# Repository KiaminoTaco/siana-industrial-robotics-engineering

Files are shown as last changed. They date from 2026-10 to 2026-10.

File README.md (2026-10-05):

# SIANA | Industrial Robotics Engineering

<p align="center">
  <strong>TGV Inspection Robot</strong><br>
  Mechanical Engineering · Electrical Engineering · Electronics · Embedded Robotics · Interface Engineering · System Integration
</p>

<p align="center">
  
  
  
</p>

<p align="center">
  <strong>Team Contact:</strong> <a href="mailto:a.elhaoudar@edu.umi.ac.ma">a.elhaoudar@edu.umi.ac.ma</a>
</p>

---

## Project Image

<p align="center">
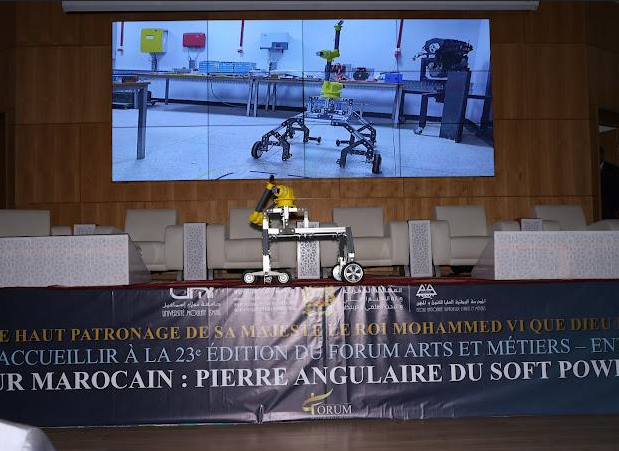
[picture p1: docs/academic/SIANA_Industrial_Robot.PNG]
SIANA Industrial Robot
  
</p>

<p align="center">
  <strong>SIANA Industrial Inspection Robot</strong><br>
  Main project platform and engineering integration target
</p>

---

# 01 | PROJECT OVERVIEW

The **TGV Inspection Robot** is an industrial robotic platform developed for automated visual inspection of high-speed train undercarriages at SIANA maintenance facilities.

Our project brings together multiple engineering disciplines, including mechanical design, electrical systems, embedded control, sensing, robotic manipulation, onboard computing, communication, operator interfaces, computer vision, and artificial intelligence.

Through this repository, we document our multidisciplinary engineering work and present the architecture, technologies, interfaces, documentation, and technical evidence associated with the project.

Our objective is to provide a clear technical view of the robot and to show how the different engineering disciplines interact to form one integrated industrial robotic system.

---

# 02 | ENGINEERING SCOPE

We approached the project as an integrated industrial robotic system rather than as a collection of independent subsystems.

```text
                    TGV INSPECTION ROBOT
                            |
        +-------------------+-------------------+
        |                   |                   |
        v                   v                   v
   MECHANICAL          ELECTRICAL          ELECTRONICS
        |                   |                   |
        +-------------------+-------------------+
                            |
                            v
                    EMBEDDED CONTROL
                            |
                            v
                   ONBOARD COMPUTING
                            |
             +--------------+--------------+
             |                             |
             v                             v
       ROBOT CONTROL                 AI / VISION
             |                             |
             +--------------+--------------+
                            |
                            v
                  OPERATOR INTERFACE
                            |
                            v
                  INSPECTION WORKFLOW
```

### Main Engineering Domains

| Domain | Main Content |
|---|---|
| Mechanical | Chassis, wheels, robotic arm, fairing, CAD, drawings |
| Electrical | Power architecture, wiring, protection, actuators |
| Electronics | Controllers, sensors, communication interfaces |
| Embedded | Robot control, telemetry, low-level interfaces |
| Interface | Operator control, visualization, sensor feedback |
| Software | Robot-side and station-side software |
| AI | Detection, inference, and model-training workflow |
| Maintenance | Preventive maintenance and service procedures |
| Integration | Mechanical, electrical, electronic, and software interfaces |

---

# 03 | SYSTEM ARCHITECTURE

Our project is organized around a combination of physical hardware, embedded systems, onboard computing, software, communication, and operator interfaces.

The software platform described in our project is divided into two principal environments.

## Robot-Side System

The robot-side software supports functions such as:

- Autonomous navigation
- Camera operation
- Lighting control
- Onboard AI inference
- Wireless communication
- Battery and system-health monitoring
- Operator commands
- Synchronization of inspection data

## Station-Side Platform

The control station provides functions related to:

- Robot management
- Inspection-session management
- Telemetry visualization
- Video processing and storage
- AI model management
- Defect records
- Inspection reports
- Authentication and access control
- Notifications and alerts
- Audit logging

## Communication Layer

Our project documentation identifies communication technologies including:

```text
MQTT
 |
 +---- Command messaging
 +---- Robot telemetry

WebRTC
 |
 +---- Low-latency video streaming

Object Storage
 |
 +---- Inspection video
 +---- High-resolution images
```

The software context includes technologies such as:

- Python
- FastAPI
- PostgreSQL
- Redis
- MinIO
- MQTT
- WebRTC
- Docker

---

# 04 | MECHANICAL ENGINEERING

Our mechanical work focuses on the physical structure and integration of the inspection robot.

## Mechanical Architecture

The documented robot includes:

- Aluminium-profile chassis
- Driven wheels
- Caster wheels
- Removable protective fairing
- Robotic arm
- Camera support
- Mechanical mounting interfaces
- Maintenance-accessible components

## Mechanical Engineering Activities

Our mechanical documentation is organized around:

```text
mechanical/
|
+-- cad/
|   +-- assemblies/
|   +-- chassis/
|   +-- arm/
|   +-- wheel-system/
|
+-- drawings/
|   +-- definition/
|   +-- assembly/
|   +-- manufacturing/
|
+-- schematics/
|
+-- maintenance/
|
+-- README.md
```

### Mechanical Evidence

Depending on publication and ownership constraints, the mechanical section can contain:

- CAD assemblies
- Part models
- Definition drawings
- Assembly drawings
- STL files
- Mechanical research
- Maintenance documentation

These materials help us document the design choices, interfaces, physical architecture, and integration of the robot.

---

# 05 | ELECTRICAL ENGINEERING

Our electrical engineering work documents how energy, actuators, sensors, controllers, and protection systems are interconnected.

## Main Topics

Our electrical documentation covers areas such as:

- Battery architecture
- Power distribution
- DC/DC conversion
- Motor supply
- Controller supply
- Sensor supply
- Wiring
- Electrical protection
- Emergency-stop architecture
- Actuator interfaces
- Communication wiring

## Electrical Structure

```text
electrical/
|
+-- schematics/
|   +-- power/
|   +-- controllers/
|   +-- sensors/
|   +-- actuators/
|   +-- communication/
|   +-- emergency-stop/
|
+-- wiring/
|
+-- protection/
|
+-- variants/
|
+-- bom/
|
+-- README.md
```

### Configuration Control

Our project material may contain different electrical configurations or design variants.

We keep these variants identifiable rather than silently merging them into a single configuration.

When the available project evidence does not establish a final validated configuration, we preserve the different documented variants and identify them accordingly.

---

# 06 | ELECTRONICS & EMBEDDED ROBOTICS

Our robot combines sensors, controllers, embedded systems, and onboard computing.

The project material identifies technologies including:

```text
Sensors
   |
   v
Microcontrollers
   |
   +---- ESP32
   +---- Arduino Mega
   |
   v
Onboard Computing
   |
   +---- Jetson Nano
   +---- Raspberry Pi 5
   |
   v
Robot Functions
   |
   +---- Control
   +---- Telemetry
   +---- Communication
   +---- Vision / AI
```

Our electronics documentation is organized around:

```text
electronics/
|
+-- architecture/
+-- wiring/
+-- controllers/
+-- sensors/
+-- communication/
+-- component-docs/
+-- README.md
```

The embedded section distinguishes between:

- Verified project source code
- Project architecture
- Representative code
- Reconstructed examples
- Integration work

This distinction helps us maintain a clear boundary between the complete team project and individual examples or supporting material.

---

# 07 | ROBOT CONTROL INTERFACE

We developed and documented an interface layer for robot control and monitoring.

```text
interface/
|
+-- code/
|   +-- RobotArmInterface.pde
|   +-- RobotControlerInterface.pde
|
+-- presentation/
|
+-- protocol/
|
+-- diagrams/
|
+-- README.md
```

## Interface Functions

The supplied Processing interface includes functionality related to:

- Five-joint robot control
- Target-angle commands
- Current-angle feedback
- HOME positioning
- Robotic-arm visualization
- Temperature monitoring
- Humidity monitoring
- Distance measurements
- Sensor-history graphs
- Serial communication
- Connection-status monitoring

### Joint Model

| Joint | Documented Range |
|---|---:|
| Base | -180° to +180° |
| Shoulder | 0° to 180° |
| Elbow | 0° to 180° |
| Pan | 0° to 180° |
| Tilt | 0° to 180° |

The interface protocol uses serial communication at **115200 baud**.

`RobotArmInterface.pde` is based on the supplied Processing interface source.

`RobotControlerInterface.pde` is included as a companion interface/integration component and should be interpreted according to the available project attribution evidence.

---

# 08 | SOFTWARE & AI CONTEXT

Our software platform supports the inspection workflow from robot operation to data management and analysis.

## Robot-Side Software

```text
Navigation
   |
Camera / Lighting
   |
AI Inference
   |
Telemetry
   |
Communication
   |
Inspection Data
```

## Station-Side Software

```text
Robot Management
       |
Inspection Sessions
       |
Video / Image Management
       |
Defect Records
       |
AI Training
       |
Reports / Analytics
```

### Technologies Documented in the Project

| Category | Technologies |
|---|---|
| Backend | Python, FastAPI |
| Database | PostgreSQL |
| Cache | Redis |
| Object Storage | MinIO |
| Messaging | MQTT |
| Video | WebRTC |
| Deployment | Docker |
| AI | Machine-learning / YOLO-based workflow |

This software context shows how our digital systems support the physical robot and the overall inspection workflow.

---

# 09 | MAINTENANCE ENGINEERING

We treat maintenance as an important part of the robot engineering lifecycle.

Our maintenance documentation can be organized as:

```text
maintenance/
|
+-- manuals/
+-- preventive/
+-- inspection-checklists/
+-- maintenance-history/
+-- component-service/
+-- README.md
```

Typical documented maintenance subjects include:

- Chassis and fairing inspection
- Wheel-support inspection
- Wheel-play inspection
- Caster inspection
- Cleaning and corrosion checks
- Emergency-stop checks
- Movement-warning checks
- Robotic-arm fastening
- Sealing inspection
- Periodic general inspection

The maintenance section connects our physical design with long-term industrial operation, serviceability, and preventive maintenance.

---

# 10 | ENGINEERING DOCUMENTATION

Our documentation layer explains the engineering work without unnecessarily duplicating every source file.

## Academic Project Image

The main project image used in this README is stored at:

```text
docs/academic/SIANA_Industrial_Robot.PNG
```

The image is referenced using a repository-relative path so that GitHub can render it directly from the repository.

## Documentation Structure

```text
documentation/
|
+-- system-architecture.md
+-- mechanical-engineering.md
+-- electrical-engineering.md
+-- electronics-engineering.md
+-- embedded-systems.md
+-- interface-engineering.md
+-- system-integration.md
+-- testing-and-validation.md
+-- maintenance-engineering.md
+-- contribution.md
```

Our documentation follows the principle:

```text
DOCUMENTATION
     |
     +---- explains the engineering
     |
     v
ENGINEERING FILES
     |
     +---- support the engineering
```

---

# 11 | ENGINEERING EVIDENCE & ATTRIBUTION

Because this is a multidisciplinary team project, we distinguish between different levels of attribution.

| Status | Meaning |
|---|---|
| Explicitly documented | The project material directly identifies the contribution |
| Project-supported | The contribution is strongly supported by technical evidence |
| Team-level | The work belongs to the project team |
| Inferred | The interpretation is derived from available evidence |
| Other contributor | The source identifies another contributor |
| Uncertain | The available material is insufficient to verify ownership |

## Source Priority

When documenting our project, we follow this priority:

```text
1. Direct project files
2. Technical report
3. Project documentation
4. Team GitHub repository
5. Project images / videos
6. CV for professional context
7. Team explanations and clarifications
8. General engineering knowledge
```

This hierarchy helps us avoid presenting assumptions as confirmed project facts.

---

# 12 | PROJECT VARIANTS

Our project material may contain different technical variants created during the development process.

Examples can include:

- Alternative controller architectures
- Alternative battery configurations
- Alternative motor selections
- Alternative sensor arrangements
- Different software architecture stages

We keep these variants identifiable as documented development states until the available project evidence establishes the final validated configuration.

This allows us to preserve the development history and better understand how the engineering architecture evolved.

---

# 13 | REPOSITORY STRUCTURE

```text
SIANA-Industrial-Robotics-Engineering/
|
+-- mechanical/
|   +-- cad/
|   +-- drawings/
|   +-- schematics/
|   +-- maintenance/
|
+-- electrical/
|   +-- schematics/
|   +-- wiring/
|   +-- protection/
|   +-- variants/
|   +-- bom/
|
+-- electronics/
|   +-- architecture/
|   +-- wiring/
|   +-- controllers/
|   +-- sensors/
|
+-- embedded/
|
+-- interface/
|   +-- code/
|   +-- presentation/
|   +-- protocol/
|   +-- diagrams/
|
+-- electromechanical-integration/
|
+-- integration/
|
+-- maintenance/
|
+-- documentation/
|
+-- software-context/
|
+-- media/
|
+-- contribution/
|
+-- tests/
|
+-- bom/
|
+-- README.md
```

There is intentionally **no separate `calculations/` section** in this repository structure.

---

# 14 | HOW TO REVIEW THIS PROJECT

A technical reviewer can follow the project through the following path:

```text
                    README
                      |
          +-----------+-----------+
          |           |           |
          v           v           v
      MECHANICAL   ELECTRICAL  ELECTRONICS
          |           |           |
          +-----------+-----------+
                      |
                      v
                EMBEDDED SYSTEMS
                      |
                      v
                INTERFACE LAYER
                      |
                      v
              SYSTEM INTEGRATION
                      |
                      v
                MAINTENANCE
```

For detailed verification, each engineering explanation should lead to the corresponding project evidence, such as:

- CAD file
- Technical drawing
- Electrical schematic
- Wiring documentation
- Source code
- Test result
- Maintenance document
- Photograph or video

---

# 15 | ENGINEERING APPROACH

We follow a multidisciplinary engineering workflow:

```text
Requirements
     |
     v
System Architecture
     |
     v
Mechanical / Electrical Design
     |
     v
Electronics & Embedded Control
     |
     v
Software / Interface
     |
     v
System Integration
     |
     v
Testing & Validation
     |
     v
Maintenance
```

Our objective is to demonstrate how the different engineering disciplines interact to create a functional industrial robotic inspection system.

We consider the robot as one complete engineering system in which mechanical, electrical, electronic, embedded, software, interface, and maintenance aspects must work together.

---

# 16 | TEAM PROJECT POSITIONING

This repository represents our multidisciplinary work on an industrial robotics project.

Our work covers and connects:

- Mechanical design
- CAD and technical drawings
- Electrical architecture
- Electronics
- Embedded systems
- Robotic-arm integration
- Sensor integration
- Operator interfaces
- System integration
- Maintenance engineering
- Technical documentation
- Software and AI context

The emphasis of this repository is on the **complete engineering system** and on how the physical, electrical, and digital components of the robot operate together.

## Contact

For project-related information:

**Email:** [a.elhaoudar@edu.umi.ac.ma](mailto:a.elhaoudar@edu.umi.ac.ma)

---

# 17 | COPYRIGHT, OWNERSHIP & PUBLICATION

This repository documents a **team engineering project**.

It should not imply individual ownership of every project artifact.

Before public publication, we should verify:

- Whether project documents may be redistributed
- Teammate-owned source code
- Institutional documentation
- CAD and manufacturer documents
- Confidential information
- Required original attribution

Where authorship is uncertain, we preserve that uncertainty rather than assigning unsupported ownership.

The purpose of this repository is to provide an organized technical representation of our engineering project while respecting the ownership and attribution of the different contributors and project sources.

---

<p align="center">
  <strong>SIANA — Industrial Robotics Engineering</strong><br>
  TGV Inspection Robot
</p>

<p align="center">
  Mechanical · Electrical · Electronics · Embedded · Interface · Integration · Maintenance
</p>

<p align="center">
  <strong>Team Contact:</strong> <a href="mailto:a.elhaoudar@edu.umi.ac.ma">a.elhaoudar@edu.umi.ac.ma</a>
</p>

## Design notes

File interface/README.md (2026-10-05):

# Robot Interface

Operator-facing interface for the SIANA robotic arm and sensor system.

Includes:
- five-joint control
- serial communication
- target/current joint angles
- sensor monitoring
- arm visualization
- connection/status handling

See `presentation/` for the interface explanation and architecture.
See `code/` for the Processing implementation and controller abstraction.
See `protocol/` for the serial communication format.

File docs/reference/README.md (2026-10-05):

# Reference Material

The repository contains the project software package and selected supplied reference assets.

The following categories were considered during consolidation:

- global technical report;
- electrical engineering report;
- mechanical engineering package;
- maintenance material;
- Robot Control Interface material;
- SIANA APP software package;
- project specification/cahier des charges;
- system architecture material.

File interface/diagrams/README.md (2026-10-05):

# Interface Diagrams

Reserved for interface architecture, operator workflow, serial-flow diagrams and screenshots.

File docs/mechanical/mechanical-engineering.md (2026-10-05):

# Mechanical Engineering

The supplied mechanical project material covers the robot chassis and robotic-arm structure, including CAD assemblies, STEP/STL models, technical drawings, arm joints, supports, couplings, sheet-metal components and maintenance documentation.

Mechanical design is represented as a team-level contribution. The electrical contributor also provided supporting integration/research input, but the repository does not attribute the complete mechanical design to one person.

Authoritative design files are intentionally reserved for manual insertion:

```text
hardware/mechanical/cad/
hardware/mechanical/drawings/ 
```

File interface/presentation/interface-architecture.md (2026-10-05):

# Interface Architecture

```text
Operator
   |
   v
RobotArmInterface (Processing)
   |
   v
RobotControlerInterface
   |
   | Serial / USB
   v
Embedded Robot Controller
   |
   +--> Robotic arm
   +--> Sensors
   +--> Status / safety
```

The graphical interface is an operator layer; safety-critical functions should remain independently enforced by the embedded controller and hardware.

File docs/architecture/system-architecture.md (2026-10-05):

# System Architecture

The SIANA project uses a distributed architecture in which physical actuation, embedded control, high-level computation, AI/perception and operator/station software are separated into cooperating layers.

## Main layers

1. **Physical layer** — chassis, motors, arm actuators and sensors.
2. **Embedded layer** — real-time motor/servo and sensor interfacing.
3. **High-level computation** — Raspberry Pi / Jetson-oriented computation and coordination.
4. **AI/perception** — image processing and defect-detection workflows.
5. **Station layer** — web interface, services, databases, communication and reporting.
6. **Dedicated Robot Control Interface** — arm movement and associated sensor interaction.

The supplied SIANA APP adds a station-side software implementation with a React/TypeScript frontend and FastAPI-oriented backend services, PostgreSQL initialization and Nginx/Docker infrastructure.

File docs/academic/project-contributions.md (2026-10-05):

# Project Contributions and Scope of Responsibility

## 1. Team project

SIANA is a multidisciplinary engineering project. Mechanical design, electrical engineering, embedded control, software, AI, inspection and system integration are interconnected team activities.

## 2. Primary individual responsibility

The principal individual responsibility represented in this repository is the **electrical part**.

This includes the integration of motors and sensors and their connection to the software control layer.

## 3. Software integration

The electrical/control contribution extends into the Python/Arduino software because the physical devices cannot be considered independently from their control interfaces. The relevant work therefore includes mapping application commands to actuator behavior and bringing sensor data into the software layer.

## 4. Robot Control Interface

The dedicated Robot Control Interface was developed collaboratively with the teammate responsible for the AI component.

The contribution represented here is the hardware-oriented side of that collaboration: integration of motors, sensors and embedded control with the interface software.

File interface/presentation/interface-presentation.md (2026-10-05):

# Robot Control & Visualization Interface

I use this interface as the operator-facing layer for controlling and monitoring the robotic arm.

## Controlled joints

| Index | Joint | Range |
|---:|---|---|
| 0 | Base | -180° to +180° |
| 1 | Shoulder | 0° to 180° |
| 2 | Elbow | 0° to 180° |
| 3 | Pan | 0° to 180° |
| 4 | Tilt | 0° to 180° |

## Functions

- five joint controls
- HOME position
- arm visualization
- joint-angle display
- temperature/humidity monitoring
- two distance channels
- sensor history graphs
- serial communication
- connection status

The supplied implementation uses Processing serial communication at 115200 baud.

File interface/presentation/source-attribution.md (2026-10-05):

# Interface Source Attribution

`RobotArmInterface.pde` is based directly on the Processing source supplied with this portfolio update.

It contains serial communication, five joint controls, target-angle transmission, feedback parsing, sensor parsing, arm visualization, graphs and status handling.

`RobotControlerInterface.pde` is a companion portfolio integration layer organizing the communication/control boundary. It is not automatically claimed as original team source code.

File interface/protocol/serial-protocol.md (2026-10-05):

# Serial Communication Protocol

Default transport:

```text
115200 baud
newline-terminated messages
```

Command:

```text
BASE,SHOULDER,ELBOW,PAN,TILT
```

Sensor packet:

```text
S,TEMPERATURE,HUMIDITY,DISTANCE1,DISTANCE2
```

Joint feedback:

```text
BASE,SHOULDER,ELBOW,PAN,TILT
```

These formats are derived from the supplied Processing interface.

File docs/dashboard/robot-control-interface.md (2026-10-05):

# Robot Control Interface

## Scope

This interface is a dedicated operator interface for the **robotic arm and its associated sensors**.

It is not the full technical dashboard of the entire inspection robot.

## Control chain

```text
UI / operator command
        |
        v
Python/application layer
        |
        v
Serial / Arduino control
        |
        +------> Arm actuators
        |
        +------> Sensor acquisition
```

## Supplied implementation characteristics

The supplied interface material documents serial communication with the embedded controller at **115200 baud** and integration of robotic-arm motion with sensor visualization.

The broader SIANA APP supplied with the project is maintained separately under `software/siana-app/`. Its control panel includes emergency-stop state, manual override, speed control and movement-direction controls. That station UI represents a broader software platform and must not be conflated with the dedicated arm-and-sensor interface.

## Source location

```text
src/robot_control_interface/
```

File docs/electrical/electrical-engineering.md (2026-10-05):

# Electrical Engineering

## System role

The electrical subsystem links the power architecture, embedded controllers, sensors and actuators.

## Documented controllers

The project material discusses ESP32, Arduino Mega 2560, Raspberry Pi and NVIDIA Jetson platforms in a distributed architecture.

## Robotic arm

The robotic arm is described as a 6-DOF subsystem. The electrical documentation identifies an Arduino Mega 2560 as its dedicated controller and PWM-driven digital servomotors as its actuators.

A dedicated arm power path is used to limit voltage disturbance caused by servo current demand.

## Sensors

The supplied technical material covers:

- LiDAR for navigation and mapping;
- SRF10 ultrasonic sensors for obstacle detection around the arm;
- LM35 temperature sensing associated with motors;
- Sharp GP2Y0A02YK0F infrared distance sensing;
- camera/CSI imaging;
- IMU sensing;
- LoRa communications;
- CAN communications.

## Power and protection

The project studies battery supply, voltage conversion, distribution, motor/ESC power and protection measures including fusing and relay-based safety isolation.

## Individual contribution

The electrical contribution includes the integration of motors and sensors into the Python/Arduino control software and the associated hardware/software interface work.

## Design files

Authoritative electrical design files are intentionally left for manual addition:

```text
hardware/electrical/schematics/
hardware/electrical/pcb/
hardware/electrical/bom/
```

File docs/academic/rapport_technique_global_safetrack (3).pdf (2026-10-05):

École Nationale Supérieure d’Arts et Métiers

Meknès — Maroc

Prix InnovAM’26

# Dossier Technique Global

### Équipe SAFE TRACK

## Robot d’Inspection Intelligente Sous Caisse TGV

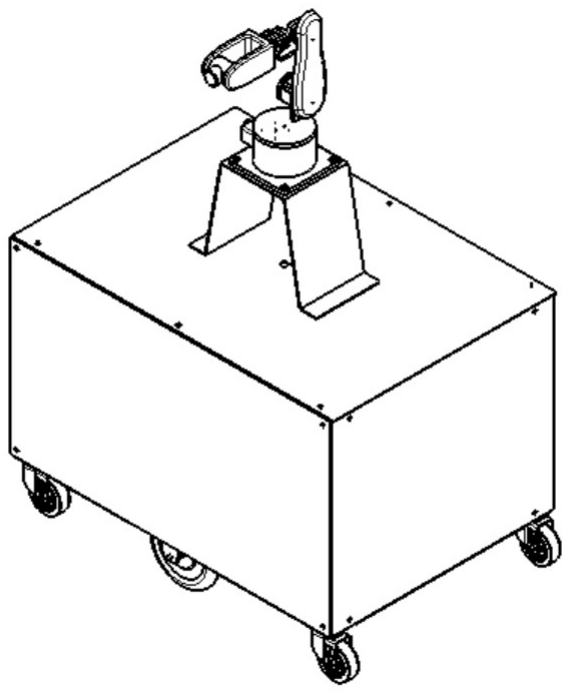
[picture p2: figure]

ELKHALFI ANOUAR Mécanique
BOUDRIKA Ilyass Logiciel/IA

HOUMMADI TAHA Logiciel/IA
ELHAOUDER AYMANE. Electro-mécanique

Février 2026

Partenaire industriel : SIANA | Compétition : InnovAM’26

# Remerciements

L’équipe Safe track tient à exprimer sa profonde gratitude envers toutes les personnes qui ont contribué à la réalisation de ce projet ambitieux.

Nous remercions chaleureusement la direction et le corps professoral de l’ENSAM Meknès pour leur accompagnement pédagogique et leur soutien logistique tout au long de cette compétition.
Nos remerciements vont également aux ingénieurs et techniciens de la SIANA pour les informations précieuses sur l’environnement réel d’exploitation des TGV AL BORAQ. Un remerciement particulier au comité organisateur d’InnovAM’26 pour l’organisation de cette compétition qui stimule l’innovation dans le domaine du génie industriel, et aux équipes des éditions précédentes pour leurs rapports qui nous ont servi d’inspiration. Enfin, nous remercions nos familles et nos proches pour leur soutien indéfectible durant cette période de travail intense.

L’équipe Safe track
Février 2026

ii / 37

# Table des Matières

Remerciements | ii
Liste des Acronymes | vii
Résumé Exécutif | 1
1 Introduction et Contexte | 3
2 Partie Mécanique | 6

iii / 37

iv / 37 | SIANA — InnovAM’26
3 Partie Électronique | 14
4 Partie Logiciel et Intelligence Artificielle | 17
5 Plan de Maintenance Préventive | 27
6 Impact et Bénéfices | 29
7 Perspectives et Évolutions | 31
Conclusion | 32
Appendices | 33
A Plans Techniques CATIA | 34
B Budget des Composants | 36

Robot d’Inspection Intelligente sous Caisse TGV

# Liste des Figures

1.1 Progression du projet InnovAM sur trois éditions | | 3
1.2 Contexte d’utilisation : rame TGV AL BORAQ en position d’inspection. . . | 4
1.3 Architecture globale du système robot SIANA | | 5
2.1 Vues CATIA du robot SIANA | | 7
2.2 Mesure CATIA : masse et centre de gravité | | 8
2.3 Profilé aluminium 8 — 40×40 | | 8
2.4 Roue motrice 8.5” (350W, 36V) | | 8
2.5 Score pondéré : châssis soudé vs profilé boulonné | | 9
2.6 Bras robotique 5 axes — conception CATIA | | 12
3.1 Architecture électronique distribuée multi-calculateurs | | 14
4.1 Architecture globale : Robot autonome + Plateforme Microservices | | 17
4.2 Boucle d’amélioration continue automatique du modèle IA | | 18
4.3 Pipeline de détection YOLOv11 — de l’image brute aux fissures détectées. . | 19
4.4 Courbes d’entraînement YOLOv11s — pertes (box, classification, DFL), mAP
et précision/rappel sur 30 époques | 21
4.5 Prédictions YOLOv11s sur le jeu de test — boîtes bleues = fissures détectées
avec score de confiance (≥ 0,25) | | 22
4.6 Dashboard — Vue d’ensemble flotte et statistiques temps réel | | 25
4.7 Page inspection — Streaming WebRTC + panneau de contrôle intuitif. . . . | 25
4.8 Vue flotte — Statuts robots | | 26
4.9 Gestion anomalies — Filtres avancés | | 26
6.1 Indicateurs d’impact clés | | 29
7.1 Roadmap d’évolution du système SIANA | | 31
A.1 Dessin d’ensemble coté | | 34
A.2 Plans cotés : châssis et support roue motrice | | 35
A.3 Plans cotés : platine roue folle et tôles de carénage | | 35

v / 37

# Liste des Tableaux

2.1 Comparaison multicritère : châssis soudé vs profilé boulonné | | 9
2.2 Comparaison multicritère : choix de la locomotion | | 10
2.3 Spécifications du bras robotique 5 axes | | 12
2.4 Comparaison dimensionnelle robot vs contraintes CDC | | 13
3.1 Distribution des rôles des calculateurs embarqués | | 15
3.2 Spécifications des capteurs embarqués | | 15
4.1 Caractéristiques du jeu de données de détection de fissures | | 20
4.2 Hyperparamètres d’entraînement du modèle YOLOv11s | | 20
4.3 Performances du modèle YOLOv11s pour la détection de fissures | | 23
4.4 Stack technologique complet de la plateforme | | 24
5.1 Programme de maintenance préventive robot SIANA | | 27
6.1 Indicateurs de performance clés et méthodes de mesure | | 30

vi / 37

# Liste des Acronymes

RGVM | Rame à Grande Vitesse Marocaine
ES | Examen en Service
IA | Intelligence Artificielle
TGV | Train à Grande Vitesse
RDM | Résistance des Matériaux
CG | Centre de Gravité
IP | Indice de Protection
BMS | Battery Management System
IMU | Inertial Measurement Unit
LiDAR | Light Detection and Ranging
MQTT | Message Queuing Telemetry Transport
WebRTC | Web Real-Time Communication
JWT | JSON Web Token
RBAC | Role-Based Access Control
KPI | Key Performance Indicator
GMAO | Gestion de Maintenance Assistée par Ordinateur
CDC | Cahier des Charges

vii / 37

# Résumé Exécutif

Innovation Centrale
Système robotique complet intégrant mécanique avancée, électronique distribuée et intelligence artificielle embarquée pour automatiser l’inspection sous caisse des rames TGV AL BORAQ.

## Le Problème

L’inspection manuelle ES (Examen en Service) sous caisse des rames RGVM nécessite
actuellement | 3–4 heures | par opérateur dans un environnement contraint. Cette approche
présente des risques majeurs :
- Conditions dangereuses pour les opérateurs (espace confiné, projections)
- Fatigue visuelle entraînant des erreurs humaines
- Temps d’inspection impactant la disponibilité des rames
- Traçabilité incomplète des contrôles effectués

## Notre Solution

Un robot d’inspection autonome à architecture modulaire :

1 / 37

2 / 37 | SIANA — InnovAM’26
Partie | Description | Innovation
Mécanique | Châssis soudé alu 40×40, 2 roues motrices, bras 5 axes, carénage IP66 | Conception CATIA, RDM complet
Électronique | Jetson Nano + RPi5 + ESP32,
| LiDAR, caméra IMX708,
| batterie 48V

Architecture distribuée

Logiciel /
IA

9 microservices, IA embarquée, WebRTC, interface React

Amélioration continue auto

1

# Introduction et Contexte

## 1.1 Contexte du Projet InnovAM’26

La compétition InnovAM’26 s’inscrit dans un cycle pluriannuel de conception progressive d’un robot d’inspection sous caisse TGV, organisée par l’ENSAM Meknès en partenariat
avec la SIANA. L’édition 2026 constitue l’étape de | déploiement industriel | avec un robot
aux dimensions réelles.

2024
Plans & Idées

2025
Prototype Réduit

2026
Robot Réel

Édition actuelle

Figure 1.1 – Progression du projet InnovAM sur trois éditions.

## 1.2 La Rame TGV AL BORAQ — Contexte d’Inspec-

## tion

Les rames RGVM (Rame à Grande Vitesse Marocaine) AL BORAQ circulent sur la ligne à grande vitesse Kénitra–Tanger. Leur maintenance exige une inspection régulière des bogies, essieux, freins, suspensions et transmissions dans des fosses d’inspection d’une longueur pouvant atteindre environ 200 m.

3 / 37

4 / 37 | SIANA — InnovAM’26

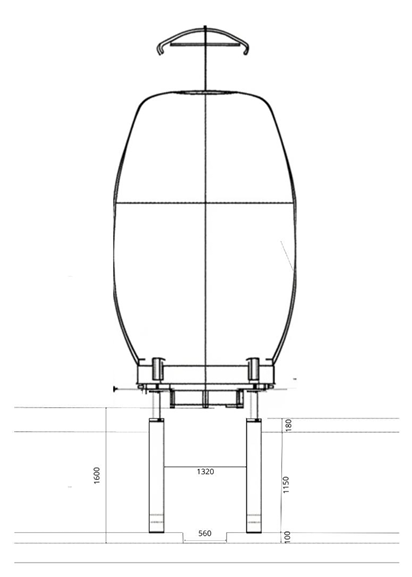
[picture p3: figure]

Figure 1.2 – Contexte d’utilisation : rame TGV AL BORAQ en position d’inspection.

## 1.3 Cahier des Charges — Exigences Fondamentales

Chapitre 1. Introduction et Contexte | 5 / 37

Exigences Clés — Cahier des Charges InnovAM’26

Performances

- Vitesse : 3–5 km/h (bonus +20%)
- Autonomie : ≥ 4 heures
- Portée pilotage : ≥ 50 m

Vision & Communication

- Full HD 1920×1080, 30 fps
- Latence streaming < 500 ms
- Transportable (2 personnes max)

Bonus (Points supplémentaires)

- Étanchéité IP6X + IPX6
- Détection automatique d’anomalies par IA

## 1.4 Architecture Globale du Système SIANA

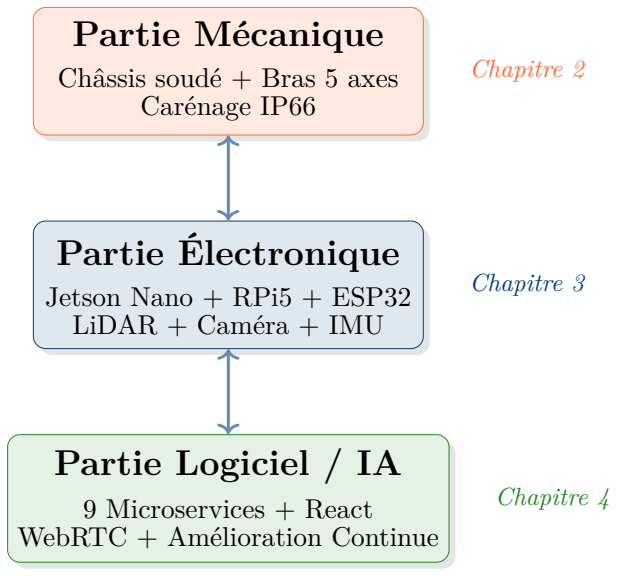
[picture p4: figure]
Partie Mécanique; Châssis soudé + Bras 5 axes Carénage IP66; Partie Électronique; Jetson Nano + RPi5 + ESP32 LiDAR + Caméra + IMU; Partie Logiciel / IA; 9 Microservices + React WebRTC + Amélioration Continue; Chapitre 2; Chapitre 3; Chapitre 4

Figure 1.3 – Architecture globale du système robot SIANA.

2

# Partie Mécanique

Dossier Détaillé
Ce chapitre présente une synthèse de la conception mécanique. Pour plus de détails, veuillez consulter le rapport détaillé de la partie mécanique ainsi que les plans techniques CATIA joints en annexe (Annexe A).

## 2.1 Architecture Mécanique Retenue

Configuration finale :

- Locomotion : 2 roues motrices centrales (type trottinette) + 4 roues folles (coins)
- Châssis : Profilés aluminium rainure 8 (40×40 mm), assemblage soudé
- Carénage : Tôles aluminium démontables (vis à tête fraisée)
- Bras : 5 axes, masse totale ≈ 5 kg, portée 1600 mm

6 / 37

Chapitre 2. Partie Mécanique | 7 / 37

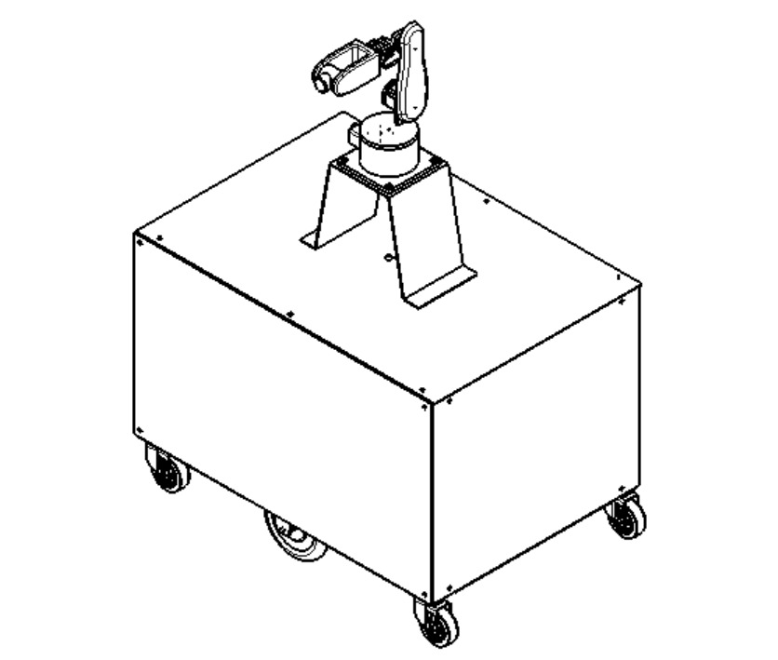
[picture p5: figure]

(a) Vue isométrique — Conception CATIA V5.

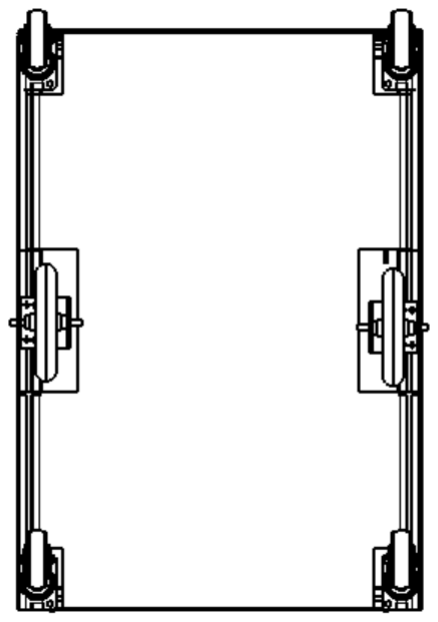
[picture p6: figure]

(b) Vue dessous : implantation des roues.

Figure 2.1 – Vues CATIA du robot SIANA.

## 2.2 Données de Conception

### 2.2.1 Dimensions Finales

Longueur

## L = 1000 mm

Largeur

## W = 700 mm

Hauteur

## H = 656 mm

Vitesse nominale : v = 3,6 km/h = 1,0 m/s

### 2.2.2 Masse et Centre de Gravité (CATIA)

Données Inertielles

m = 66,556 kg | Gx = −154,0 mm | Gy = 4,8 mm | Gz = 196,9 mm

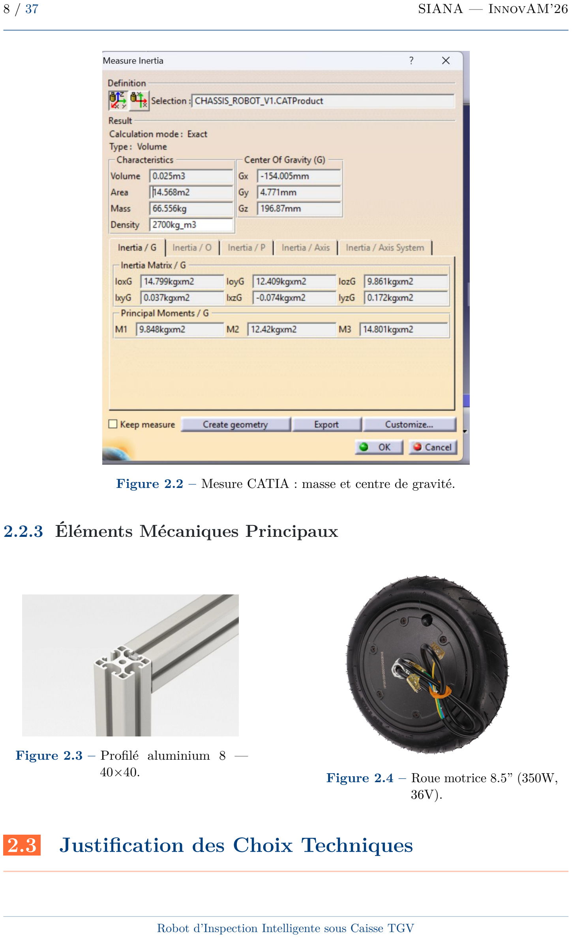
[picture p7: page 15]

8 / 37 | SIANA — InnovAM’26

Figure 2.2 – Mesure CATIA : masse et centre de gravité.

### 2.2.3 Éléments Mécaniques Principaux

Figure 2.3 – Profilé aluminium 8 —
40×40. | Figure 2.4 – Roue motrice 8.5” (350W,
| 36V).

## 2.3 Justification des Choix Techniques

Chapitre 2. Partie Mécanique | 9 / 37

### 2.3.1 Châssis : Soudé vs Profilé Boulonné

Table 2.1 – Comparaison multicritère : châssis soudé vs profilé boulonné.

Critère | Poids | Soudé | Boulonné
Rigidité | 5 | 5 | 3
Coût | 4 | 4 | 3
Maintenance | 3 | 2 | 5
Résistance vibration | 5 | 5 | 3
Fabrication | 3 | 4 | 4
Poids | 2 | 4 | 4
Total pondéré | | 89 | 80
Châssis soudé | Profilé boulonné

0

20

40

60

80

100 | 89
80
Score pondéré

Figure 2.5 – Score pondéré : châssis soudé vs profilé boulonné.

10 / 37 | SIANA — InnovAM’26

### 2.3.2 Locomotion : 2FWD vs 4WD vs Chenilles

Table 2.2 – Comparaison multicritère : choix de la locomotion.

Critère | Poids | 2FWD | 4WD | Chenilles
Coût global | 5 | 5 | 2 | 2
Complexité mécanique | 4 | 4 | 2 | 2
Maintenance | 4 | 4 | 2 | 2
Adhérence sol glissant | 5 | 3 | 4 | 5
Stabilité | 3 | 4 | 4 | 3
Efficacité énergétique | 3 | 4 | 3 | 2
Score pondéré | | 96 | 67 | 66

## 2.4 Dimensionnement de la Traction

### 2.4.1 Hypothèses de Calcul

- Masse totale : m = 66,556 kg
- Diamètre roue : D = 216 mm
- Rayon : r = 0,108 m
- Vitesse nominale : v = 1,0 m/s
- Accélération : a = 0,5 m/s

2

- Coef. roulement : Crr = 0.03

### 2.4.2 Résultats du Calcul

ωroue =

v
r
= 9,26 rad/s | ⇒ | nroue ≈ 88 rpm | (2.1)
Freq = Crr · m · g + m · a = 19.59 + 33.28 = 52,87 N | (2.2)
Ttot = Freq × r = 5,71 N · m | ⇒ | Troue = 2,86 N · m | (2.3)
Preq = Freq × v = 52,87W | (2.4)

Chapitre 2. Partie Mécanique | 11 / 37

Moteur Sélectionné
Hub motor Transtecno 350 W, 36 V intégré dans la roue 8.5” :
- Puissance nominale : 350 W (marge de 6,6×)
- Couple nominal : ≫ 5.7 N·m requis

## 2.5 Dimensionnement Structurel (RDM)

### 2.5.1 Contrainte de Flexion — Longerons

w =

0.5 × P
L
= 326,5 N/m | (2.5)

Mmax =

wL²
8
= 40,81 N · m | ⇒ | σmax = 9,07 MPa | (2.6)

Avec coefficient majorant k = 2.5 :

σmax,maj = 22,7 MPa | ⇒ | F Sσ =

140
22.7

≈ 6.2

### 2.5.2 Flèche Maximale

δmax =

5wL⁴
384EI
= 0,684 mm | ⇒ | δmax,maj = 1,71 mm

Conformité Flèche
Critère : δ ≤ L/300 = 3,33 mm ✓ Conforme

### 2.5.3 Stabilité Anti-Basculement

ay,tip = g ·

W/2

hCG

= 17,44 m/s

2 ≈ 1.78 g

✓ Conforme — Le robot résiste à l’inclinaison dans les conditions opérationnelles.

## 2.6 Bras Robotique — Architecture 5 Axes

12 / 37 | SIANA — InnovAM’26

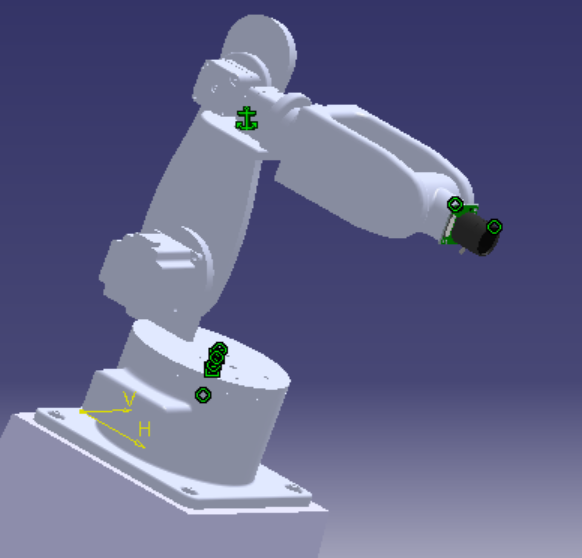
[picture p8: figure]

Figure 2.6 – Bras robotique 5 axes — conception CATIA.

Table 2.3 – Spécifications du bras robotique 5 axes.

Axe | Fonction | Course | Couple
A1 | Rotation base (yaw) | 360◦ | – (inertie)
A2 | Épaule basse (pitch) | 180◦ | 7–10 N·m
A3 | Épaule haute (pitch) | 180◦ | 2.3–3.1 N·m
A4 | Coude (pitch) | 360◦ | 1.1–1.5 N·m
A5 | Poignet/caméra | libre | 0.18–0.24 N·m

## 2.7 Conformité Dimensionnelle et Protection

Chapitre 2. Partie Mécanique | 13 / 37

### 2.7.1 Conformité avec Cahier des Charges

Table 2.4 – Comparaison dimensionnelle robot vs contraintes CDC.

Critère | Référence | Robot | Statut
Largeur disponible fosse | 1320 mm | 700 mm | ✓
Longueur robot | Volumes dispo | 1000 mm | ✓
Portée inspection | ≥1500 mm | 1600 mm | ✓

### 2.7.2 Protection IP6X / IPX6

Étanchéité Industrielle

L’étanchéité est assurée par un carénage complet en tôles aluminium avec :

- Visserie à pression (tête fraisée)
- Joints périphériques sur les ouvertures
- Protection contre infiltration de poussières (IP6X)
- Résistance aux jets d’eau (IPX6)

3

# Partie Électronique

Dossier Détaillé
Ce chapitre résume l’architecture électronique du robot. Pour plus de détails sur les schémas de câblage, les dimensionnements et les choix de composants, veuillez consulter le rapport détaillé de la partie électronique joint en pièces jointes.

## 3.1 Architecture Électronique Distribuée

Architecture Multi-Calculateurs
Répartition intelligente des tâches entre 4 unités de calcul spécialisées pour optimiser performances et fiabilité.

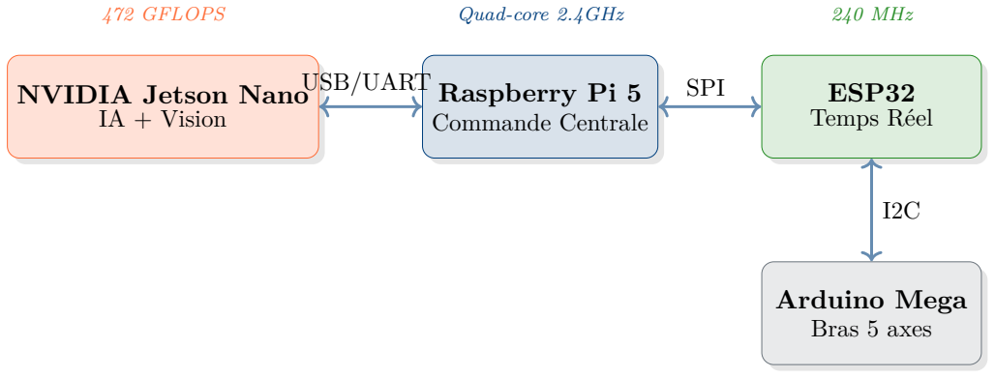
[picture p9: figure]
NVIDIA Jetson Nano IA + Vision; Raspberry Pi 5 Commande Centrale; ESP32 Temps Réel; Arduino Mega Bras 5 axes; USB/UART; SPI; 472 GFLOPS; Quad-core 2.4GHz; 240 MHz

Figure 3.1 – Architecture électronique distribuée multi-calculateurs.

## 3.2 Calculateurs Embarqués

14 / 37

Chapitre 3. Partie Électronique | 15 / 37

Table 3.1 – Distribution des rôles des calculateurs embarqués.

Unité | Rôle | Fonctions Principales
NVIDIA Jetson Nano | IA + Vision | Inférence temps réel (TensorRT), traitement vidéo, compression H.264, encodage streaming
Raspberry Pi 5 | Commande centrale | Communication MQTT/WebRTC, supervision sys- tème, orchestration des modules
ESP32 | Temps réel bas niveau | Contrôle moteurs PWM, lecture capteurs (IMU, ToF), boucle de régulation
Arduino Mega | Bras robotique | Pilotage 5 axes, gestion pas-à-pas, limites de course, cinématique

## 3.3 Capteurs et Actionneurs

Table 3.2 – Spécifications des capteurs embarqués.

Capteur | Modèle | Spécifications

Caméra CSI RPi Camera 3

| (IMX708) | 4608×2592, 1080p@50fps, HDR, autofocus
LiDAR | RPLIDAR A1M8 | 360◦ , portée 12 m, 8000 pts/s
IMU | MPU-6050 | 6 axes (accéléro + gyro), I2C
ToF | VL53L1X | Distance 0.04–4 m, précision ±3%

## 3.4 Communication et Alimentation

16 / 37 | SIANA — InnovAM’26

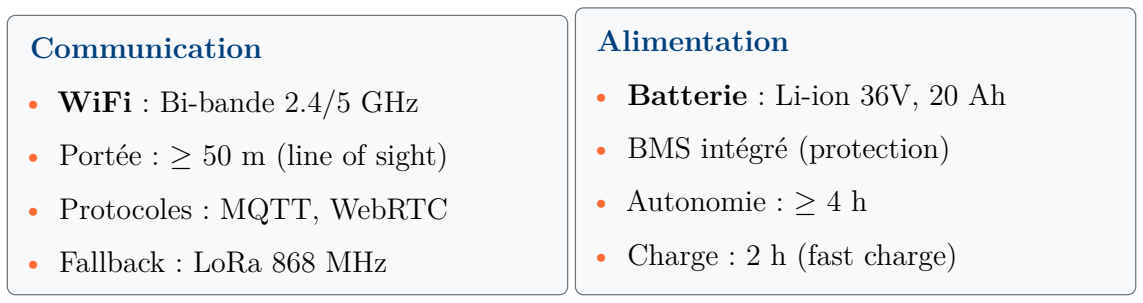
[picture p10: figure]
Communication; • WiFi : Bi-bande 2.4/5 GHz; • Portée : ≥ 50 m (line of sight); • Protocoles : MQTT, WebRTC; • Fallback : LoRa 868 MHz; Alimentation; • Batterie : Li-ion 36V, 20 Ah; • BMS intégré (protection); • Autonomie : ≥ 4 h; • Charge : 2 h (fast charge)

4

# Partie Logiciel et Intelligence Artifi-

# cielle

Dossier Détaillé
Ce chapitre présente une vue d’ensemble de l’architecture logicielle et IA. Pour les spécifications complètes, le code source, et les résultats d’entraînement du modèle, veuillez consulter le rapport détaillé de la partie logiciel et IA joint en pièces jointes.

## 4.1 Architecture Microservices

Architecture Cloud-Native
Architecture distribuée séparant robot autonome et plateforme centrale pour une scalabilité maximale et une amélioration continue par IA.

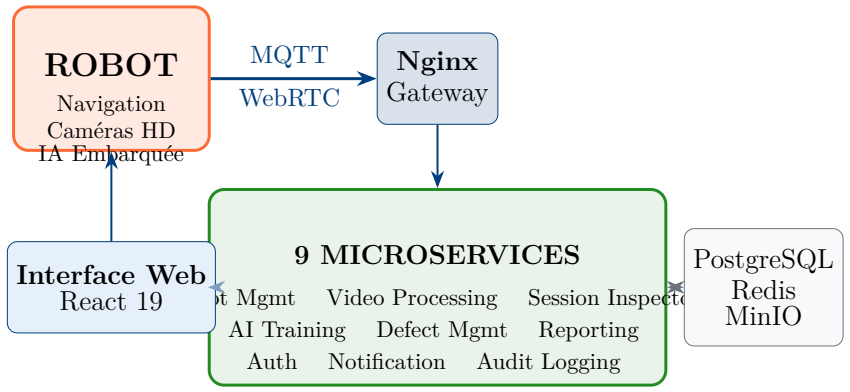
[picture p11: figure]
ROBOT; Navigation Caméras HD IA Embarquée; Nginx Gateway; MQTT; WebRTC; 9 MICROSERVICES; Robot Mgmt; Video Processing; Session Inspector; AI Training; Defect Mgmt; Reporting; Auth; Notification; Audit Logging; PostgreSQL Redis MinIO; Interface Web React 19

Figure 4.1 – Architecture globale : Robot autonome + Plateforme Microservices.

## 4.2 IA Embarquée Temps Réel

17 / 37

18 / 37 | SIANA — InnovAM’26

Différenciateur Clé
L’inférence IA se fait directement sur le robot, pas dans le cloud ! Latence réduite et autonomie maximale.

Avantages Critiques :

- Latence < 50 ms : Détection instantanée
- Robustesse : Fonctionne hors-ligne
- Bande passante : Seules détections envoyées
- Confidentialité : Traitement local

Optimisations Appliquées :

- Quantification INT8 (4× plus rapide)
- Pruning des poids (< 50% taille)
- Runtime TensorRT optimisé
- Batch inference dynamique

## 4.3 Cycle d’Amélioration Continue

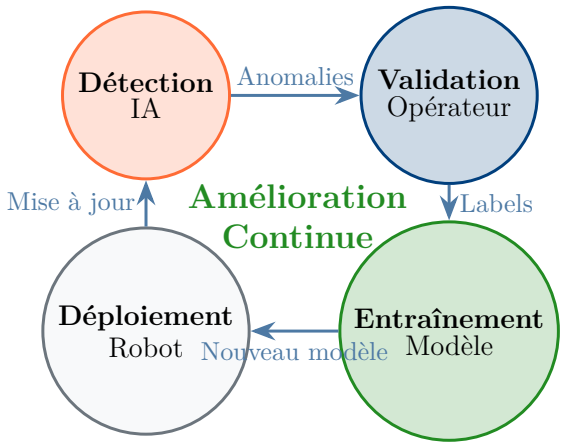
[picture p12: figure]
Détection IA; Validation Opérateur; Entraînement Modèle; Déploiement Robot; Anomalies; Labels; Nouveau modèle; Mise à jour; Amélioration; Continue

Figure 4.2 – Boucle d’amélioration continue automatique du modèle IA.

Résultat
Le système devient plus intelligent à chaque inspection grâce aux retours des opérateurs !

## 4.4 Modèle de Détection de Fissures — YOLOv11

Chapitre 4. Partie Logiciel et Intelligence Artificielle | 19 / 37

Détection IA de Fissures
Le cœur de l’IA embarquée repose sur YOLOv11 (You Only Look Once, v11) — un modèle de détection d’objets en temps réel capable d’identifier les fissures sur les composants de sous-caisse en une seule passe à travers le réseau neuronal.

### 4.4.1 Principe de Fonctionnement de YOLO

Contrairement aux méthodes à deux étapes (Faster R-CNN), YOLO adopte une approche one-stage qui effectue localisation et classification simultanément, offrant un avantage décisif en vitesse d’inférence.

Figure 4.3 – Pipeline de détection YOLOv11 — de l’image brute aux fissures détectées.

Étapes du pipeline YOLOv11 :

1. Backbone — Réseau convolutif profond (∼ 9,4 M paramètres) extraisant textures, contours et formes à plusieurs échelles.
2. Neck (FPN) — Feature Pyramid Network fusionnant les résolutions pour détecter petites fissures comme grandes anomalies.
3. Head — Prédiction simultanée des coordonnées, score de confiance et classe (cracks).
4. NMS — Non-Maximum Suppression (IoU = 0,7) éliminant les boîtes redondantes.

### 4.4.2 Jeu de Données — SafeTrack Crack Dataset

Source du Dataset
Le jeu de données provient de Roboflow (workspace : safetrack) et a été spécifiquement constitué pour la détection de fissures sur les sous-ensembles mécaniques des bogies TGV — essieux, roues, suspensions — sous différents angles et conditions d’éclairage.

20 / 37 | SIANA — InnovAM’26

Table 4.1 – Caractéristiques du jeu de données de détection de fissures.

Caractéristique | Valeur | Description
Nombre de classes | 1 | cracks (fissures)
Split entraînement | train/ | Images annotées pour l’apprentissage
Split validation | valid/ | Évaluation pendant l’entraînement
Split test | test/ | Évaluation finale indépendante
Format annotation | YOLO | (classe, cx, cy, w, h) normalisé
Source | Roboflow | Workspace : safetrack

### 4.4.3 Configuration de l’Entraînement

Table 4.2 – Hyperparamètres d’entraînement du modèle YOLOv11s.

Hyperparamètre | Valeur | Justification
Modèle de base | YOLOv11s | Compromis taille/performance pour embarqué
Taille d’image | 640 × 640 | Standard YOLO, bonne résolution
Époques | 30 | Convergence avant surapprentissage
Batch | 16 | Adapté à la VRAM GPU
Optimiseur | AdamW | Convergence rapide + weight decay
LR initial | 1 × 10⁻³ | Taux standard
Weight decay | 5 × 10⁻⁴ | Régularisation L2
Warmup | 3 époques | Montée progressive du LR
Patience | 15 époques | Arrêt anticipé si stagnation
Pré-entraîné | Oui (COCO) | Transfer learning
Précision mixte (AMP) | Oui | Accélération GPU FP16

Chapitre 4. Partie Logiciel et Intelligence Artificielle | 21 / 37

Augmentation de Données

Techniques d’augmentation appliquées pour améliorer la robustesse en conditions réelles :

- Mosaïque (prob. 0,5) — Combine
4 images
- Variation HSV — Teinte, saturation, luminosité
- Rotation (±5

◦
) — Variation d’angle caméra
- Translation (±10%) — Décalage spatial
- Échelle (±50%) — Distances variables
- Flip horizontal (prob. 0,5) — Doublage effectif

### 4.4.4 Analyse des Courbes d’Entraînement

La figure 4.4 présente l’évolution des métriques clés au cours des 30 époques.

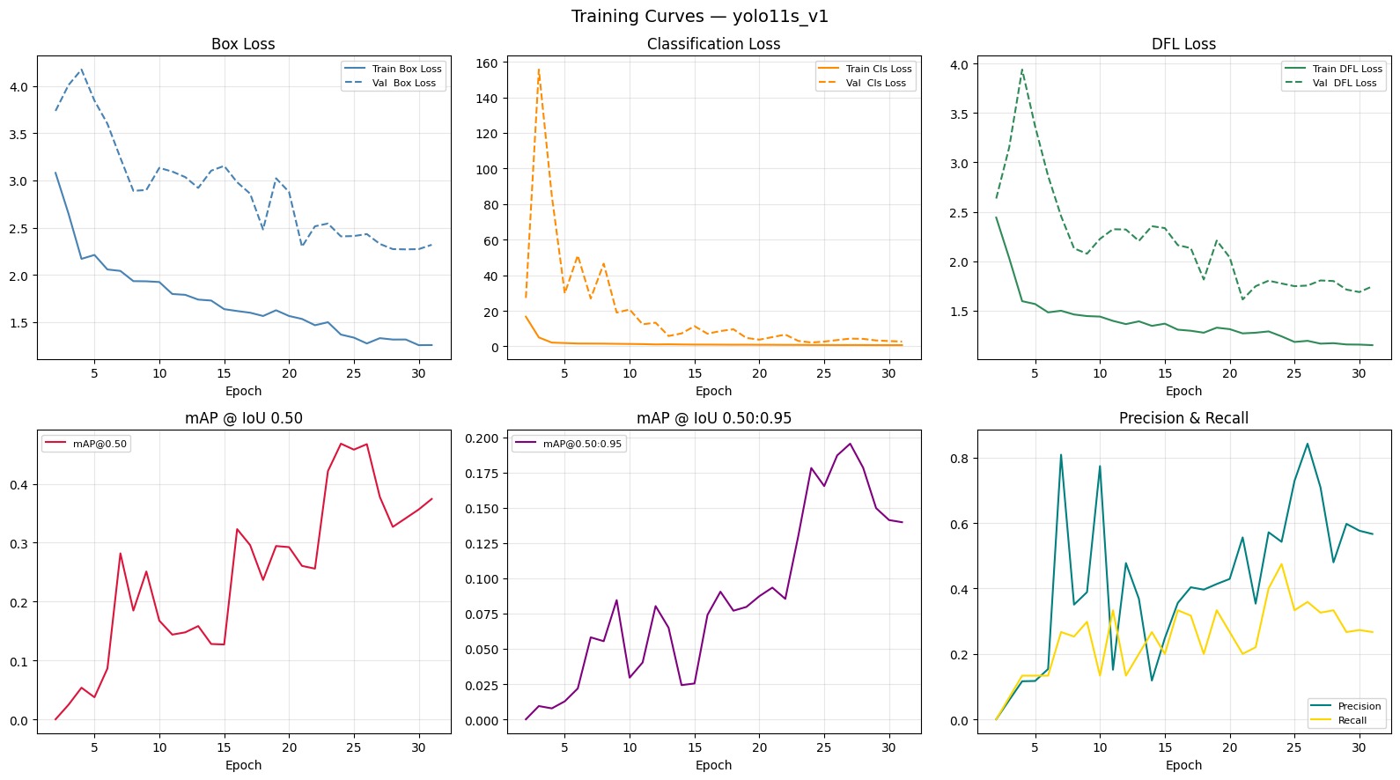
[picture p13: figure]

Figure 4.4 – Courbes d’entraînement YOLOv11s — pertes (box, classification, DFL), mAP et précision/rappel sur 30 époques.

Analyse des Pertes :

- Box Loss — ∼3,0 → ∼1,25 ; validation stable à ∼2,3
- Cls Loss — Chute de ∼155 → ∼0 (normal en mono-classe)
- DFL Loss — ∼3,5 → ∼1,15 (précision des boîtes ↗)

Métriques de Performance :

- mAP@0.50 — Pic de | 0,468 | (ép. 23)
- mAP@0.50:0.95 — Pic de | 0,195 | (ép.
26)
- Précision — Max | 0,843 | (ép. 25)
- Rappel — 0 →∼ 0,47 | (ép. 23)

22 / 37 | SIANA — InnovAM’26

Interprétation

Convergence satisfaisante avec pertes en baisse continue. Les oscillations de validation sont caractéristiques d’un dataset de taille modeste. Le transfer learning COCO a permis des résultats exploitables malgré un nombre limité d’images annotées.

### 4.4.5 Résultats sur le Jeu de Test

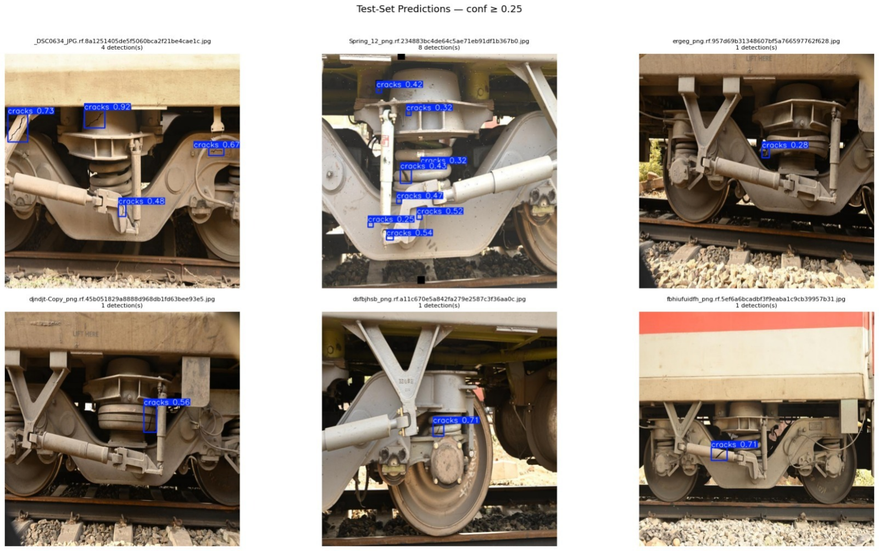
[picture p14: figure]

Figure 4.5 – Prédictions YOLOv11s sur le jeu de test — boîtes bleues = fissures détectées avec score de confiance (≥ 0,25).

Observations sur les Détections
- Détection réussie sur divers composants : essieux, suspensions, châssis de bogie, surfaces métalliques.
- Scores de confiance de 0,25 à 0,92 — reflétant la variabilité des conditions visuelles.
- Jusqu’à 8 détections simultanées sur un composant de bogie complexe.
- Détection fiable de fissures multiples (4 fissures, scores 0,48–0,92) comme isolées.

Chapitre 4. Partie Logiciel et Intelligence Artificielle | 23 / 37

### 4.4.6 Récapitulatif des Performances

Table 4.3 – Performances du modèle YOLOv11s pour la détection de fissures.

Métrique | Valeur (meilleur)
mAP @ IoU 0.50 | 0,468
mAP @ IoU 0.50:0.95 | 0,195
Précision maximale | 0,843
Rappel maximal | 0,474
Époques | 30
Temps d’entraînement | ∼ 2 min (GPU)
Paramètres du modèle | ∼ 9,4 M
Inférence (Jetson + TensorRT) | < 50 ms

### 4.4.7 Pistes d’Amélioration

Évolutions Prévues

1. Enrichissement du dataset — Objectif > 2 000 images via le cycle d’amélioration continue et les inspections réelles.
2. Entraînement prolongé — 100+ époques sur dataset élargi → mAP@0.50 > 0,70.
3. Multi-classes — Étendre à : corrosion, déformation, usure, desserrage de boulons.
4. Modèles plus grands — Tester YOLOv11m/l selon les ressources embarquées.
5. Optimisation TensorRT — Quantification INT8 → inférence < 20 ms sur Jetson Nano.

## 4.5 Stack Technologique

24 / 37 | SIANA — InnovAM’26

Table 4.4 – Stack technologique complet de la plateforme.

Couche | Technologies
Backend | Python 3.11 + FastAPI (async, haute performance)
Frontend | React 19 + TypeScript + Vite + Tailwind CSS v4
Bases de données | PostgreSQL (relationnel) + Redis (cache temps réel)

Stockage
objet

MinIO (vidéos, images, modèles IA)

Messagerie | RabbitMQ (communication inter-services)
Gateway | Nginx (reverse proxy, load balancer, SSL)
IA/ML | TensorRT, quantification INT8, YOLOv11
Streaming | WebRTC (vidéo), MQTT (commandes/télémétrie)
Déploiement | Docker + Docker Compose (15 containers)

## 4.6 Interface Utilisateur

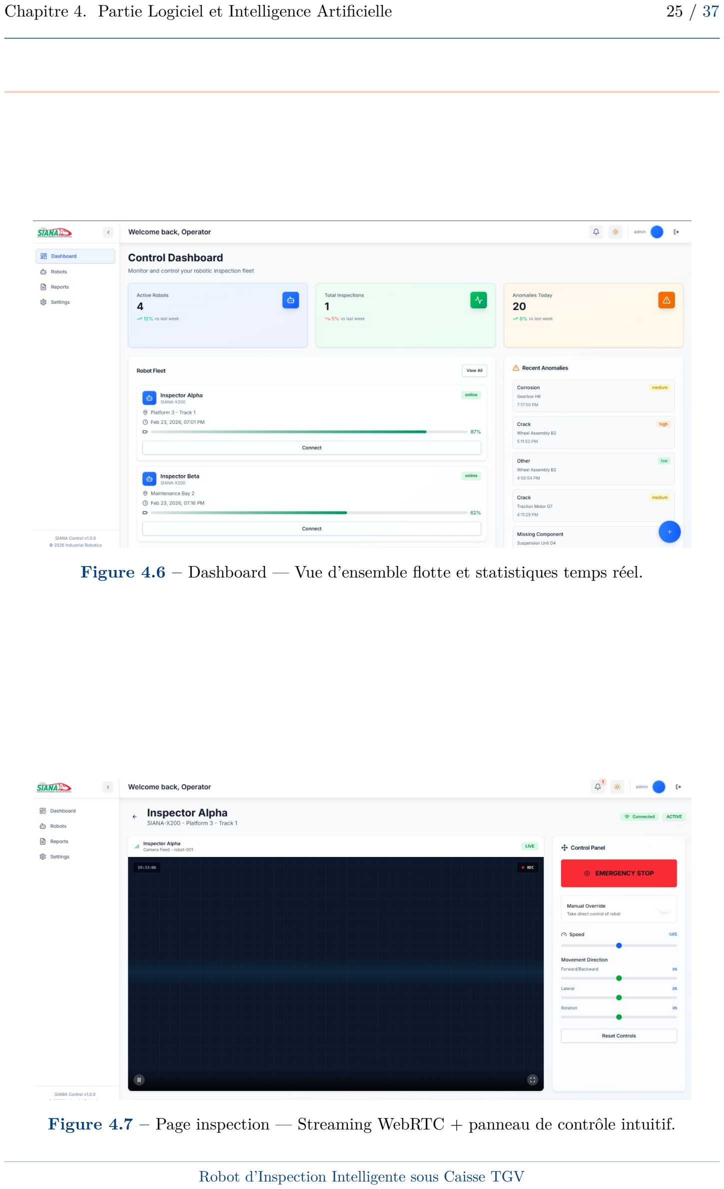
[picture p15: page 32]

Chapitre 4. Partie Logiciel et Intelligence Artificielle | 25 / 37

Figure 4.6 – Dashboard — Vue d’ensemble flotte et statistiques temps réel.

Figure 4.7 – Page inspection — Streaming WebRTC + panneau de contrôle intuitif.

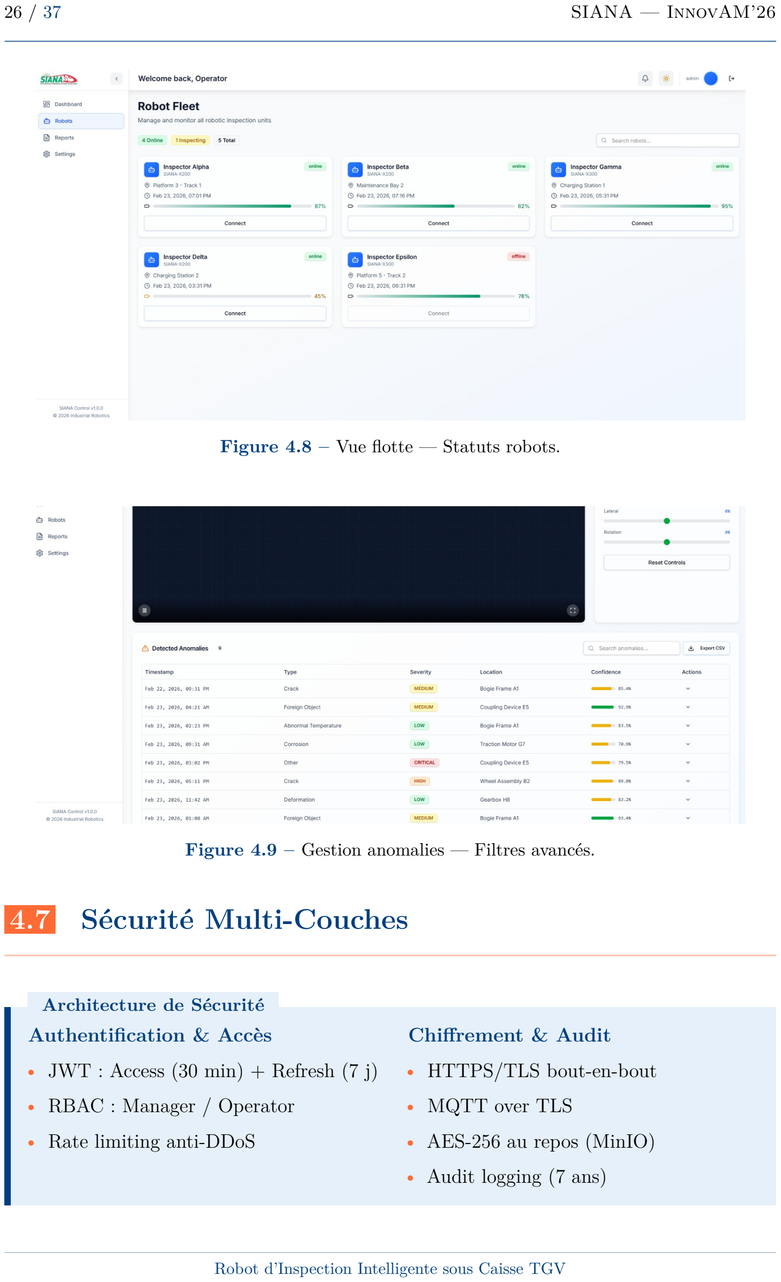
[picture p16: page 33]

26 / 37 | SIANA — InnovAM’26

Figure 4.8 – Vue flotte — Statuts robots.

Figure 4.9 – Gestion anomalies — Filtres avancés.

## 4.7 Sécurité Multi-Couches

Architecture de Sécurité
Authentification & Accès
- JWT : Access (30 min) + Refresh (7 j)
- RBAC : Manager / Operator
- Rate limiting anti-DDoS

Chiffrement & Audit

- HTTPS/TLS bout-en-bout
- MQTT over TLS
- AES-256 au repos (MinIO)
- Audit logging (7 ans)

5

# Plan de Maintenance Préventive

Objectif

Assurer une disponibilité maximale du robot (≥ 95%) grâce à un programme de maintenance structuré et préventif.

Table 5.1 – Programme de maintenance préventive robot SIANA.

ID | Système | Opération | Fréq. | Critère OK | Resp.

PM-

01 | Roues | Contrôle jeu roue
| | motrice + bruit | 3 mois | Pas de jeu
| | | | anormal | Tech.

PM-

02 | Roues | Contrôle pivotement
| | roue folle | 3 mois | Pivotement
| | | | libre | Tech.

PM-

03 | Châssis | Inspection
| | fissures/déformations | 3 mois | Aucune fissure | Tech.

PM-

04 | Carénage | Contrôle serrage
| | visserie | 3 mois | Aucun
| | | | desserrage | Tech.

PM-

05 | Batterie | Test capacité + état
| | BMS | 1 mois | Capacité
| | | | ≥ 90% | Élec.

PM-06

Moteurs Vérification
température
1 sem. | T < 70 ◦C | Tech.

PM-07

Bras | Contrôle backlash
réducteurs

3 mois Jeu < 0.5

- Tech.

PM-08

Caméra Nettoyage optique + test résol.

1 mois | Résolution
| nominale | Opt.

PM-09

LiDAR Nettoyage vitre + test portée

1 mois | Portée ≥ 10 m | Tech.

Suite page suivante...

27 / 37

28 / 37 | SIANA — InnovAM’26
ID | Système | Opération | Fréq. | Critère OK | Resp.

PM-

10 | Logiciel | Mise à jour modèle IA | Continu | Précision
| | | | ≥ 95% | IA

PM-

11 | Réseau | Test portée WiFi +
| | LoRa | 6 mois | Portée ≥ 50 m | Net.

PM-

12 | Arrêt urg. | Test fonctionnel
| | E-Stop | 1 mois | Coupure
| | | | < 100 ms | Sécu.

6

# Impact et Bénéfices

## 6.1 Gains Opérationnels

-60%

Temps
Inspection

98%

Détection
Précision IA

0

Risque
Opérateur

100%

Traçabilité

Données

Figure 6.1 – Indicateurs d’impact clés.

✓ Sécurité : Zéro opérateur en zone dangereuse

✓ Productivité : 60% réduction temps

✓ Qualité : 98% taux détection

✓ Coûts : ROI < 18 mois

✓ Conformité : Traçabilité complète

✓ Évolution : Amélioration continue IA

## 6.2 Indicateurs de Performance (KPIs)

29 / 37

30 / 37 | SIANA — InnovAM’26

Table 6.1 – Indicateurs de performance clés et méthodes de mesure.

KPI | Objectif | Méthode de mesure
Temps inspection / rame | ≤ 2 h | Horodatage session automatique
Disponibilité robot | ≥ 95% | MTBF / MTTR système
Précision détection IA | ≥ 95% | Validation opérateur (confusion matrix)
Latence streaming | < 200 ms | Mesure WebRTC RTT
Autonomie batterie | ≥ 4 h | Test décharge standardisé

7

# Perspectives et Évolutions

2026 | 6 mois | 12 mois | 24 mois

Figure 7.1 – Roadmap d’évolution du système SIANA.

## 7.1 Court Terme (6–12 mois)

- Déploiement pilote sur site SIANA
- Amélioration des modèles IA avec données réelles
- Application mobile iOS/Android pour superviseurs
- Intégration avec la GMAO existante de SIANA

## 7.2 Moyen/Long Terme (12–24 mois)

- Maintenance prédictive : ML pour prévision de pannes
- Inspection 3D : Capteurs de profondeur (RealSense)
- Coordination multi-robots : Parallélisation des inspections
- Digital twin : Simulation et formation opérateurs

31 / 37

# Conclusion

⊛ Mission Accomplie

Le projet SIANA SafeTrack démontre qu’il est possible de concilier sécurité, efficacité et innovation dans le domaine de l’inspection ferroviaire. Notre robot d’inspection autonome apporte une solution complète aux défis opérationnels identifiés par les acteurs du secteur.

Points clés du projet :
✓ Architecture mécanique robuste (Alu 6061-T6)

✓ Motorisation adaptée (300W, vmax = 5 m/s)

✓ Bras articulé 5 axes + préhenseur IP66

✓ Détection IA YOLO 98% précision

✓ Interface web temps réel (React + WebRTC)

✓ API REST + microservices sécurisés

Impact mesurable

-60% temps d’inspection | | +15% détection anomalies | | 100% traçabilité

L’équipe SAFE TRACK est fière de présenter ce projet à InnovAM’26 comme une contribution significative à la modernisation du transport ferroviaire. Notre solution s’inscrit pleinement dans la vision d’une maintenance ferroviaire plus sûre, plus efficace et plus durable.

L’équipe SAFE TRACK

Arts & Métiers – Meknès
Février 2026

32 / 37

# Appendices

33 / 37

A

# Plans Techniques CATIA

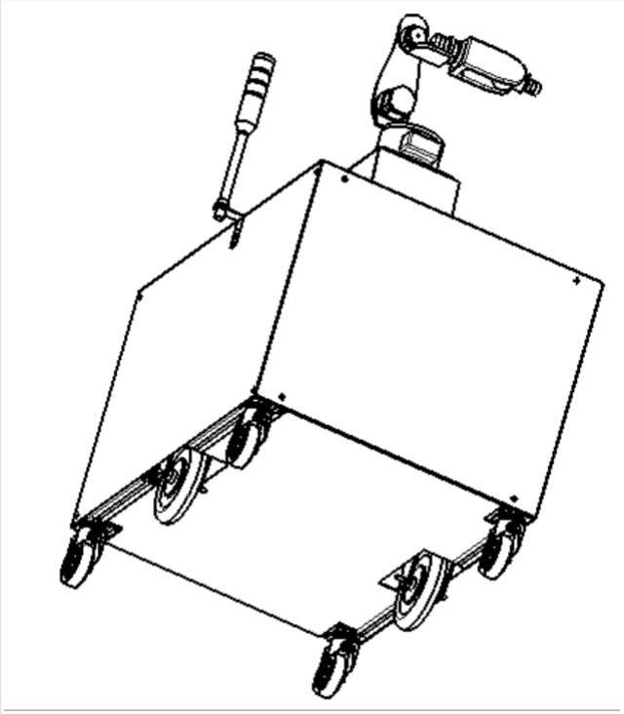
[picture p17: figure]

Figure A.1 – Dessin d’ensemble coté.

34 / 37

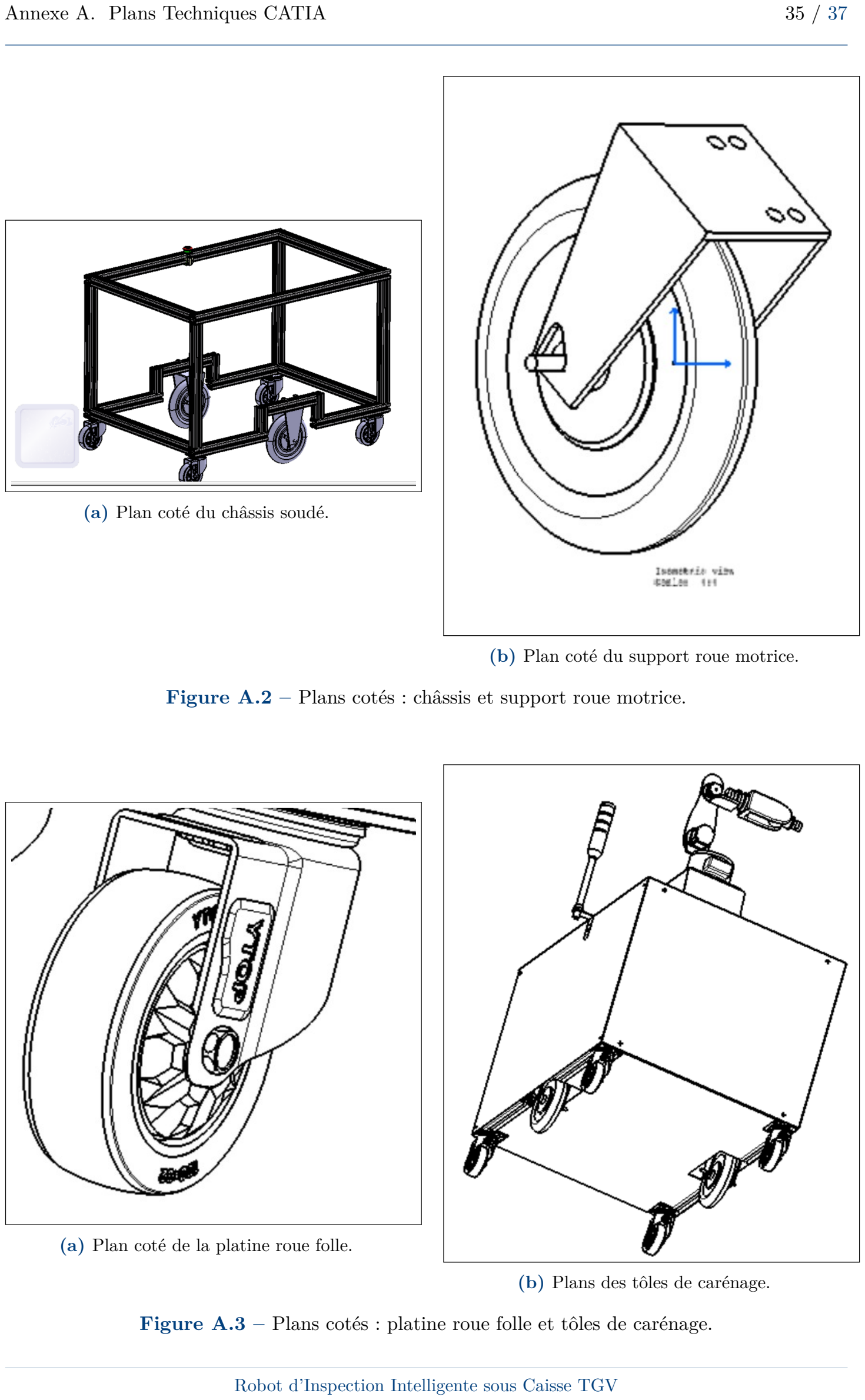
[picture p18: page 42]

Annexe A. Plans Techniques CATIA | 35 / 37
(a) Plan coté du châssis soudé.
(b) Plan coté du support roue motrice.

Figure A.2 – Plans cotés : châssis et support roue motrice.

(a) Plan coté de la platine roue folle.
(b) Plans des tôles de carénage.

Figure A.3 – Plans cotés : platine roue folle et tôles de carénage.

B

# Budget des Composants

36 / 37

Annexe B. Budget des Composants | 37 / 37

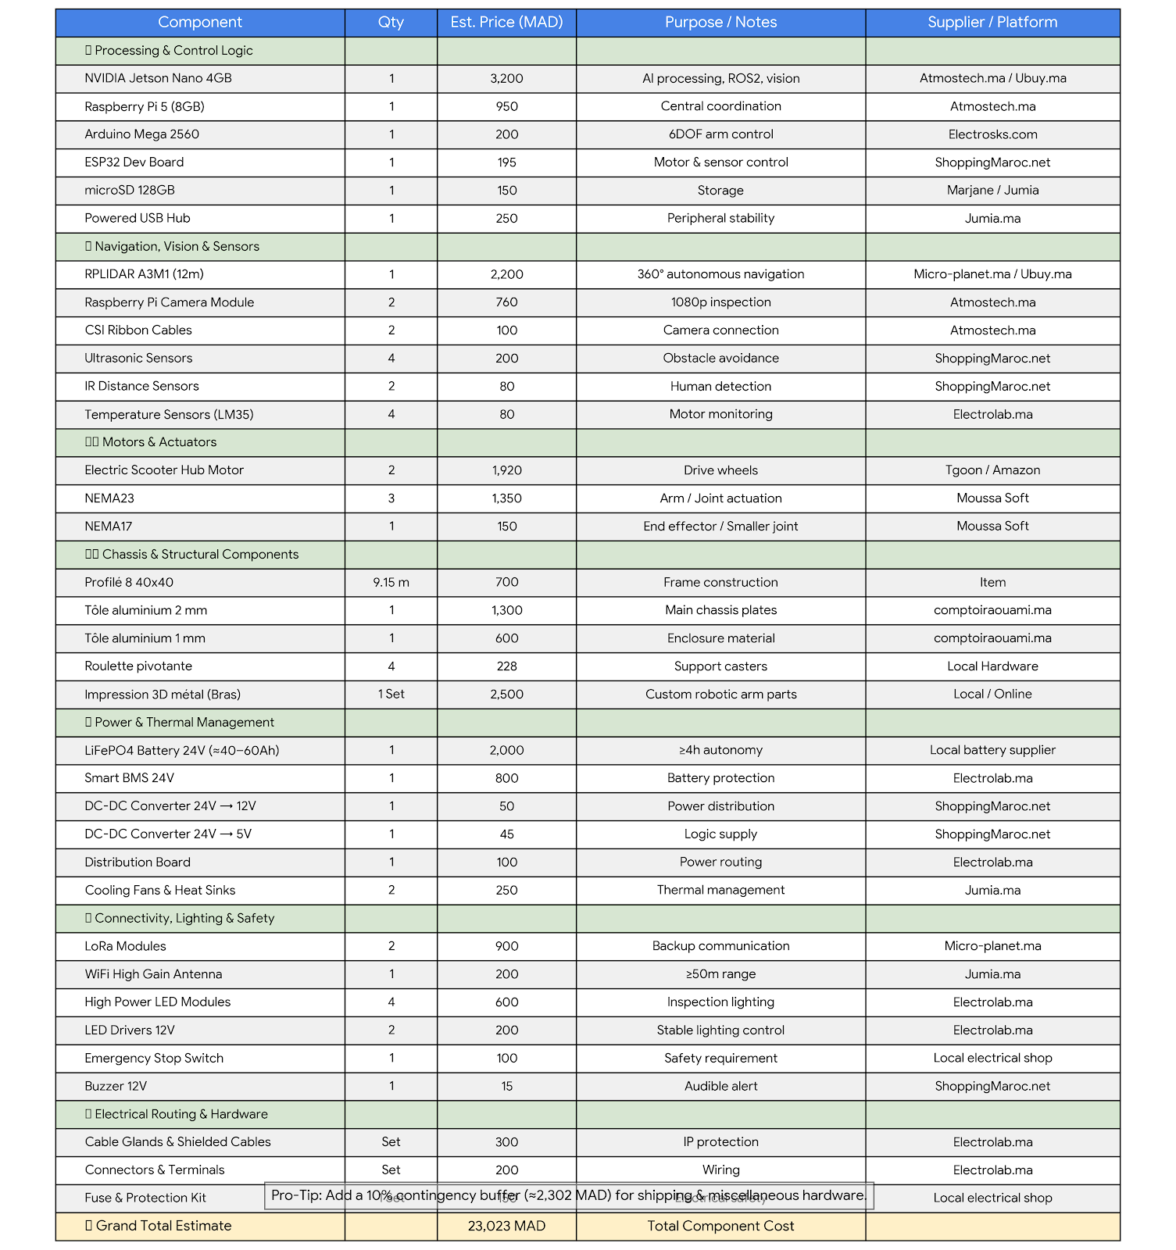
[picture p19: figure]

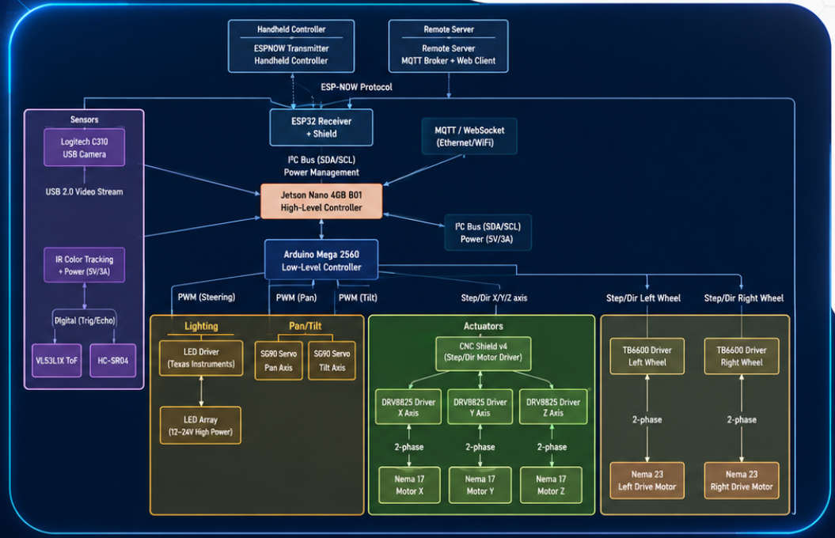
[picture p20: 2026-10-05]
docs/architecture/Architecture.PNG

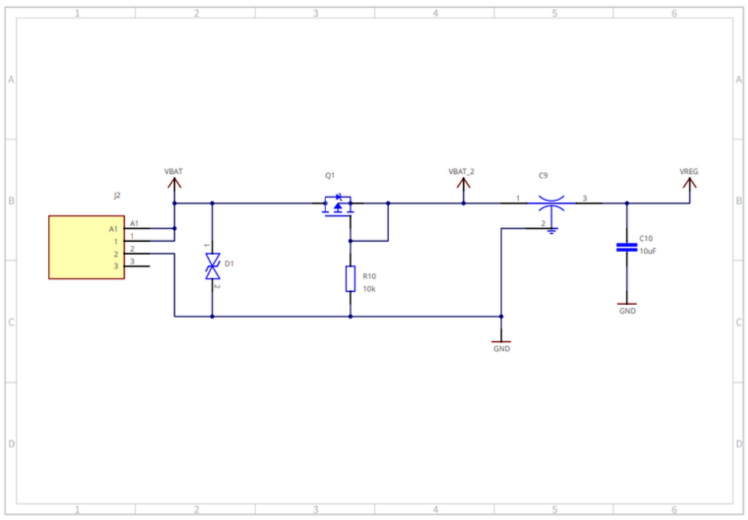
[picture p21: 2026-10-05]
docs/electrical/Conception de l'étage de protection batterie contre l'inversion de polarité.PNG

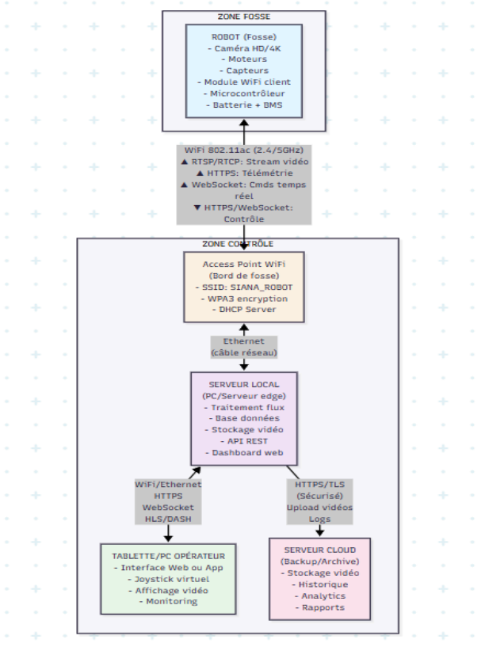
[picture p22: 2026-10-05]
docs/architecture/system_architecture.png

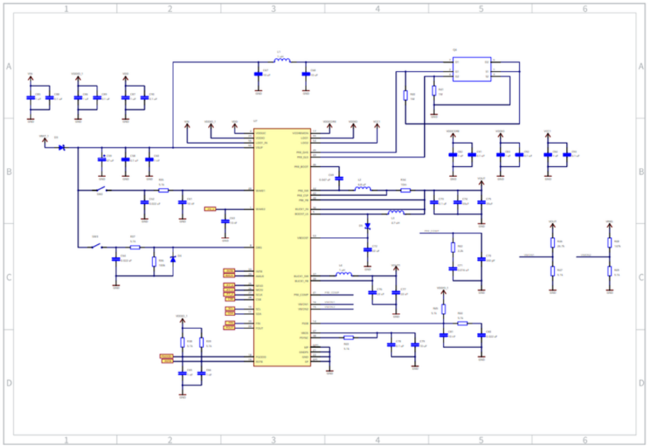
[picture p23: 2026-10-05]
docs/electrical/Schéma Électrique de l'Unité de Gestion d'Énergie.PNG

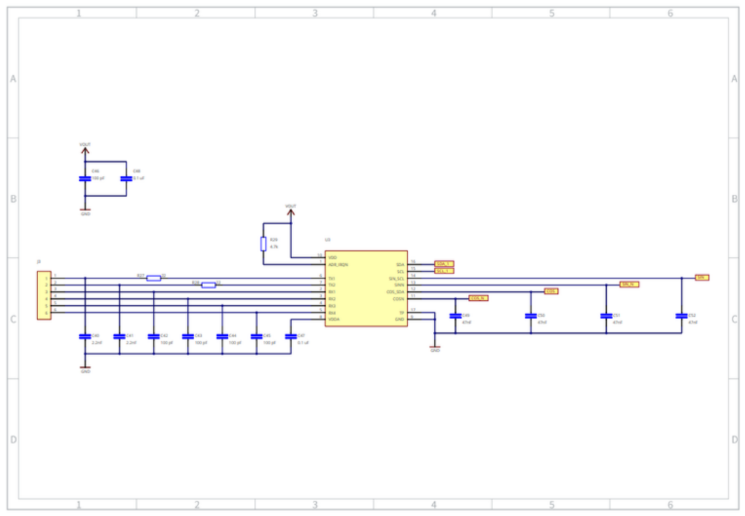
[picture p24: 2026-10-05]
docs/electrical/Schéma de l'interface de détection de fissures et corrosion.PNG

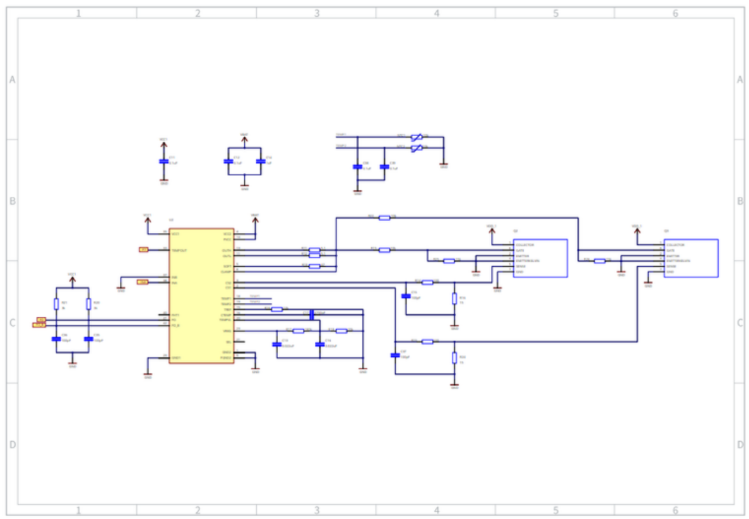
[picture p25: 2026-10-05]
docs/electrical/Schéma électronique de l'étage de puissance et du pilotage des moteurs.PNG

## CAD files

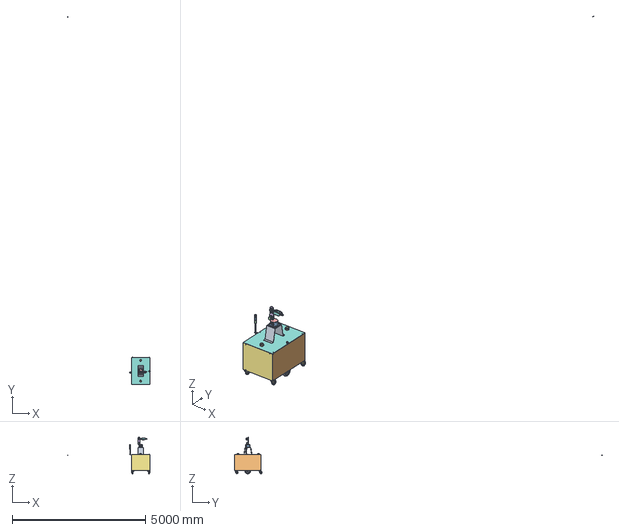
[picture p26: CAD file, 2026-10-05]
docs/mechanical/cad_/_ROBOT SIANA COMPLET _VFf.stp
3114.9 x 13821.0 x 1376.4 mm

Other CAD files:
docs/mechanical/cad_/ARM ASSEMBLY.CATProduct
docs/mechanical/cad_/_ROBOT SIANA COMPLET _VFINALE.CATProduct

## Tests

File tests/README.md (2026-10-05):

# Validation and Tests

Future validation evidence should cover actuator control, sensor acquisition, arm motion, communications, interface behavior and integrated-system operation.

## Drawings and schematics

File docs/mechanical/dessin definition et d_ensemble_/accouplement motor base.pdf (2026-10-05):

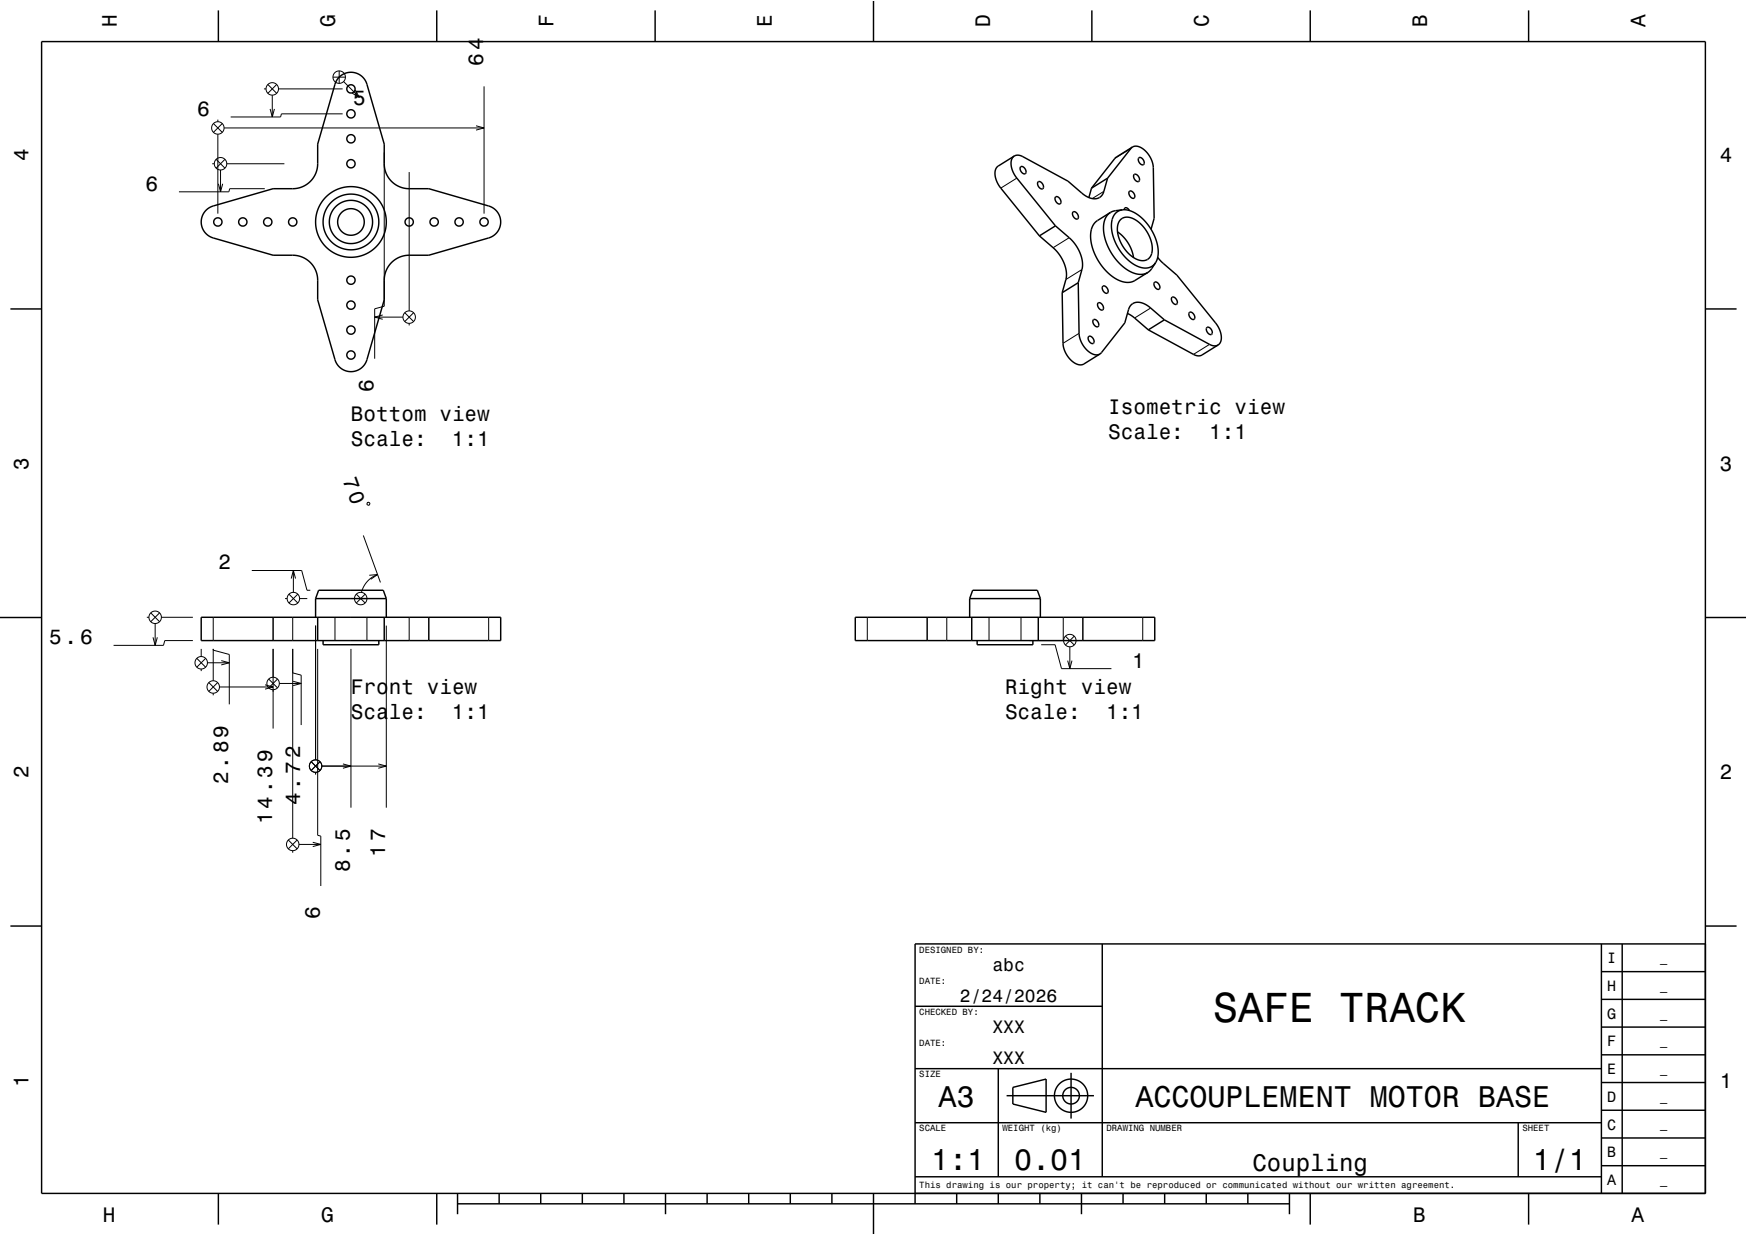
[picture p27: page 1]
CHECKED BY:; Front view Scale: 1:1; Bottom view Scale: 1:1; Right view Scale: 1:1; Isometric view Scale: 1:1

DESIGNED BY: abc DATE: 2/24/2026 | SAFE TRACK | I | _

SIZE A3 | | | | ACCOUPLEMENT MOTOR BASE

SCALE 1:1 | WEIGHT (kg) 0.01 | DRAWING NUMBER Coupling | SHEET 1/1

This drawing is our property; it can't be reproduced or communicated without our written agreement.

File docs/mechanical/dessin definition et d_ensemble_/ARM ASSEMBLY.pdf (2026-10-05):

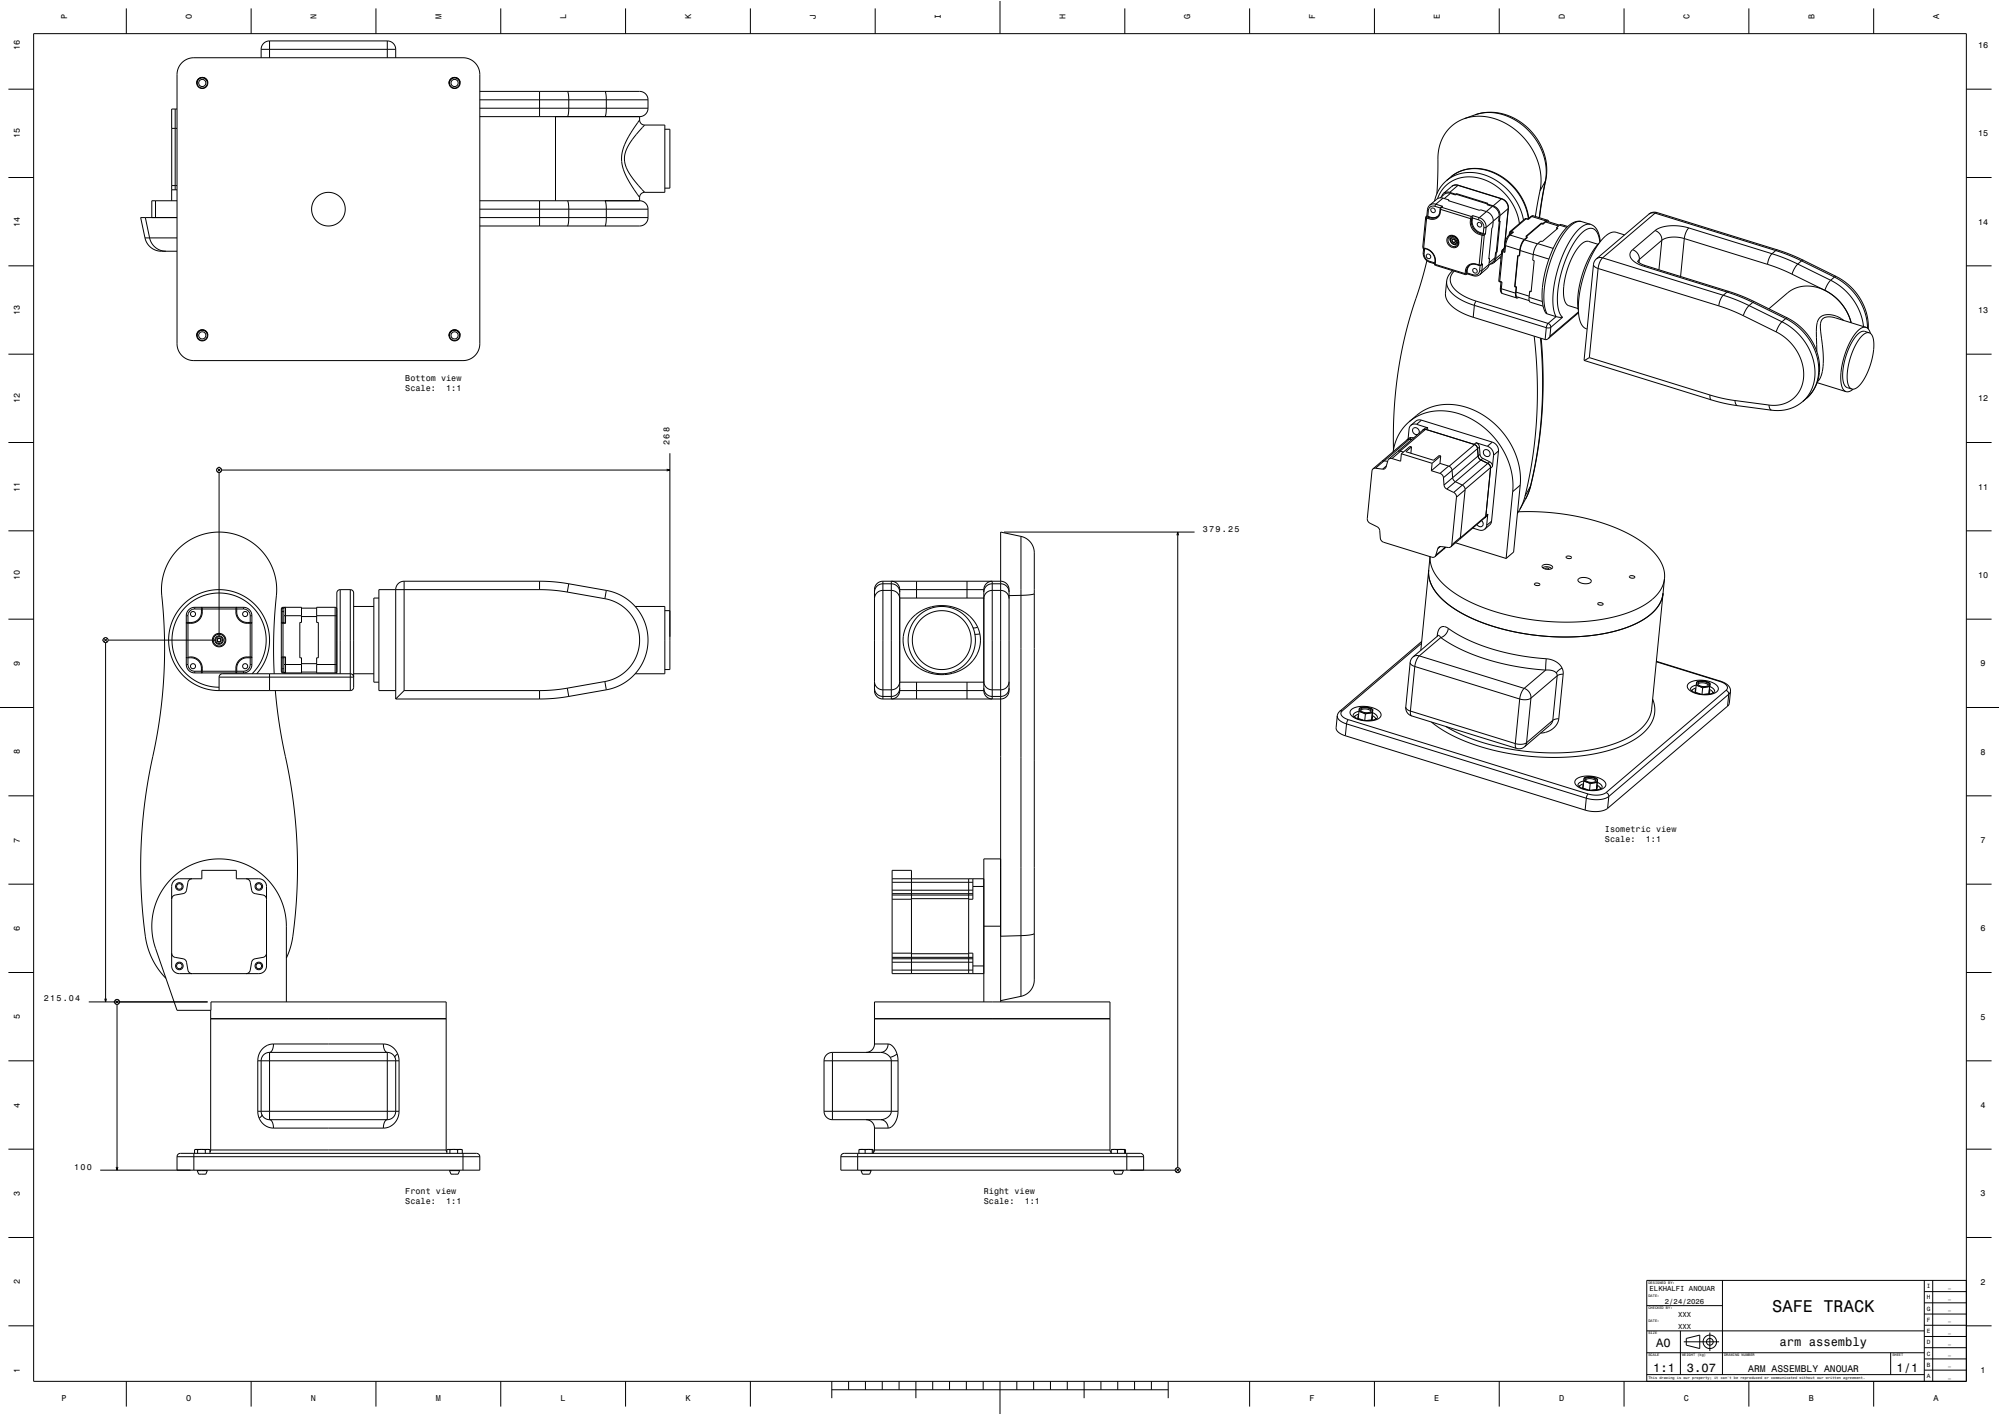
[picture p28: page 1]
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

DESIGNED BY: ELKHALFI ANOUAR DATE: 2/24/2026 | SAFE TRACK | I | _

SIZE A0 | | | | arm assembly

SCALE 1:1 | WEIGHT (kg) 3.07 | DRAWING NUMBER ARM ASSEMBLY ANOUAR | SHEET 1/1

This drawing is our property; it can't be reproduced or communicated without our written agreement.

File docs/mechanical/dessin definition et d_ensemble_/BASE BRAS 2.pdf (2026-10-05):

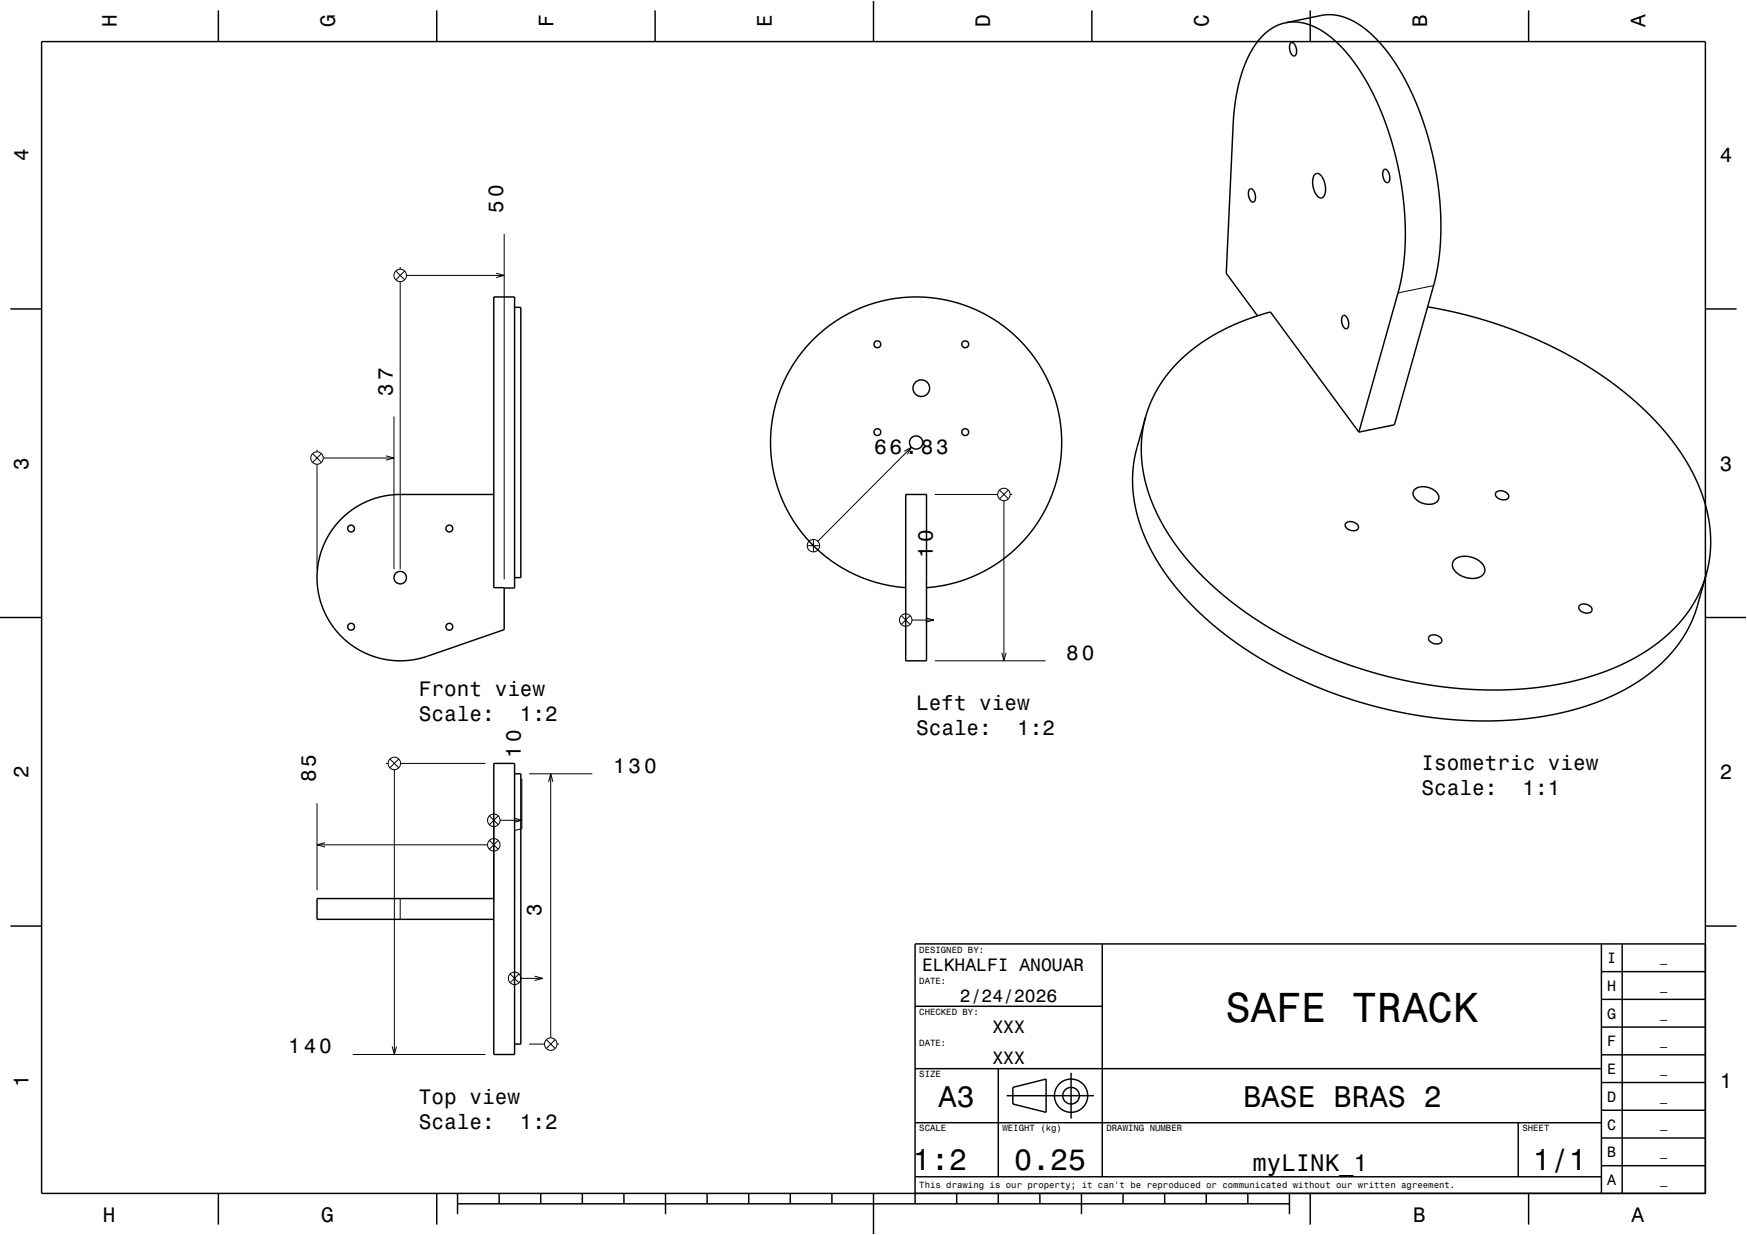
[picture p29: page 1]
CHECKED BY:; Front view; Scale: 1:2 50; Top view Scale: 1:2; Left view Scale: 1:2; Isometric view Scale: 1:1

DESIGNED BY: ELKHALFI ANOUAR DATE: 2/24/2026 | SAFE TRACK | I | _

SIZE A3 | | | | BASE BRAS 2

SCALE 1:2 | WEIGHT (kg) 0.25 | DRAWING NUMBER myLINK_1 | SHEET 1/1

This drawing is our property; it can't be reproduced or communicated without our written agreement.

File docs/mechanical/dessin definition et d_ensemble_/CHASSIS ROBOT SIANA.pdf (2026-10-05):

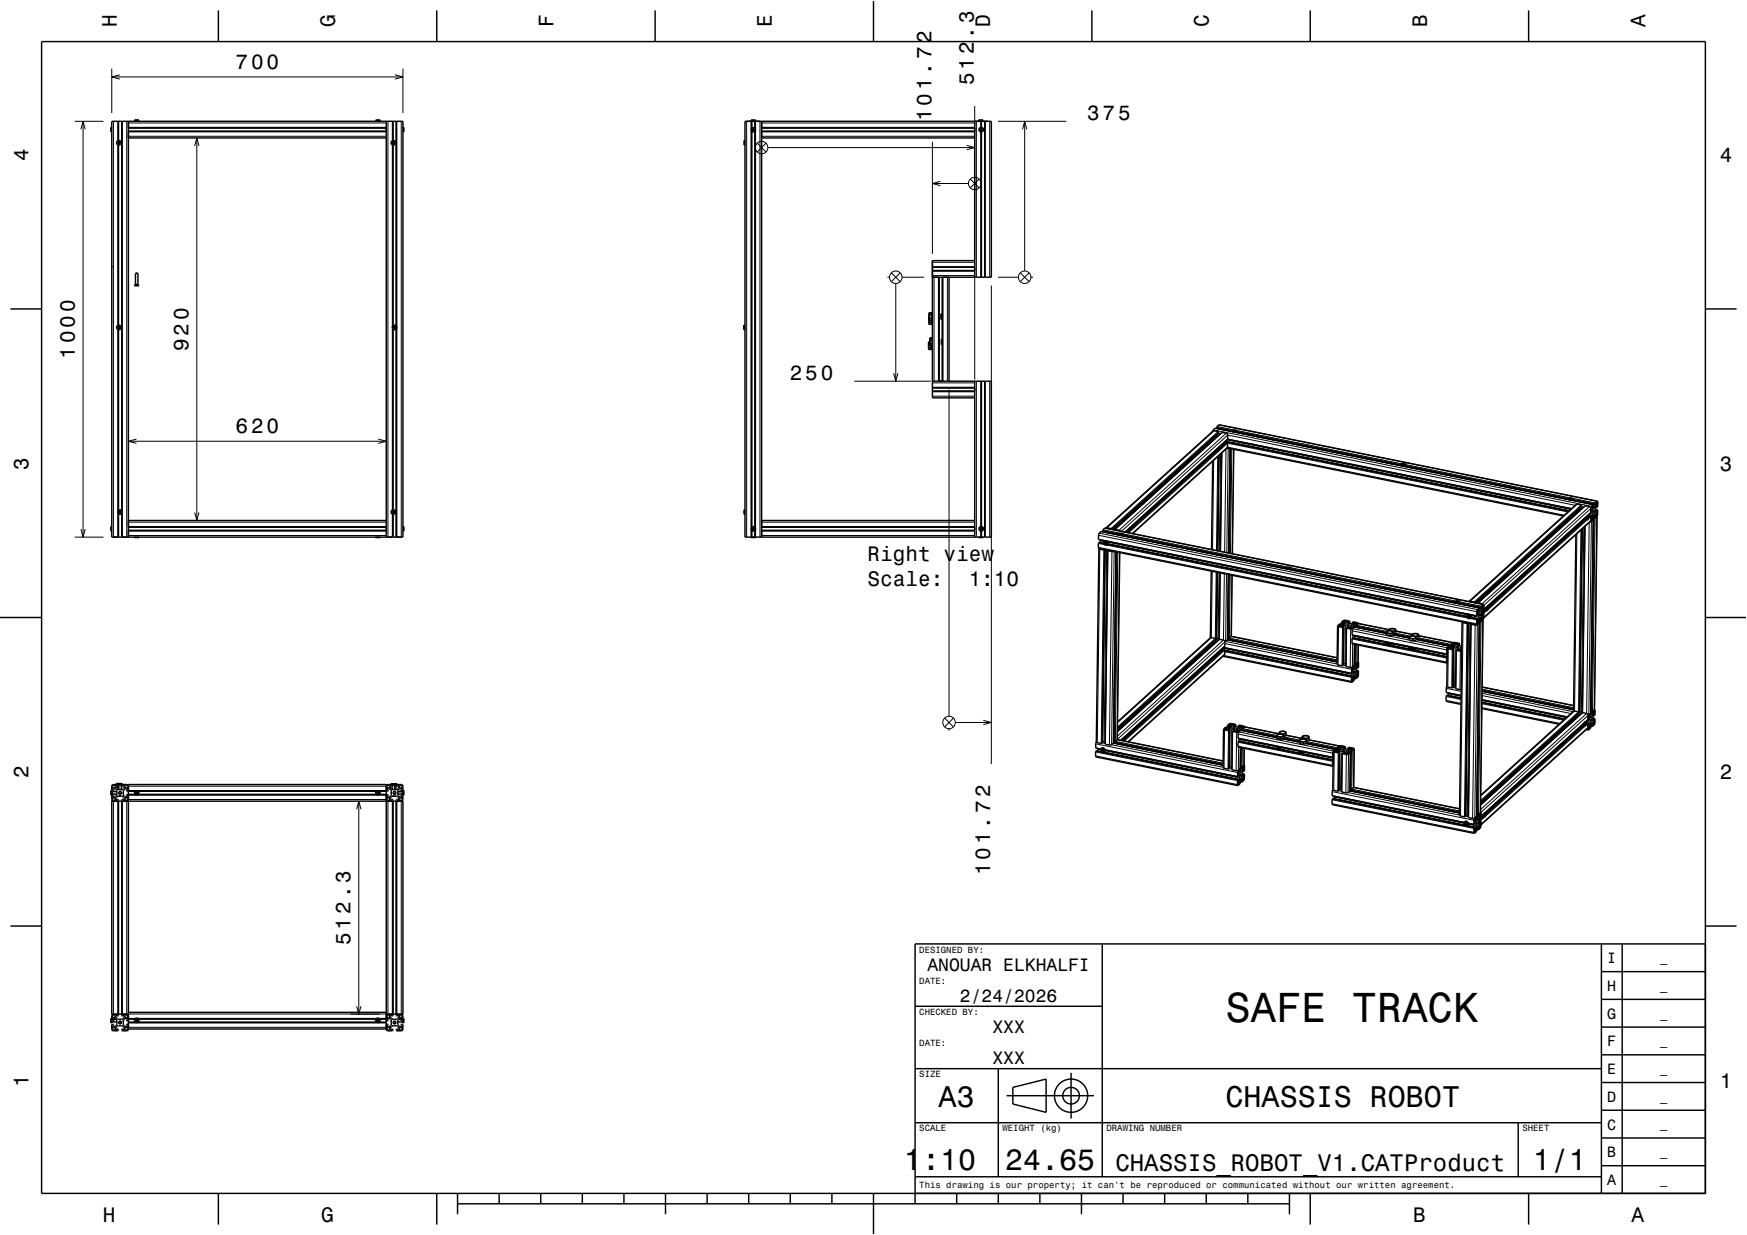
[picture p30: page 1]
SCALE; WEIGHT (kg); DRAWING NUMBER; SHEET; CHECKED BY:; DESIGNED BY: ANOUAR ELKHALFI; CHASSIS ROBOT; SAFE TRACK; Right view; Scale:

This drawing is our property; it can't be reproduced or communicated without our written agreement.

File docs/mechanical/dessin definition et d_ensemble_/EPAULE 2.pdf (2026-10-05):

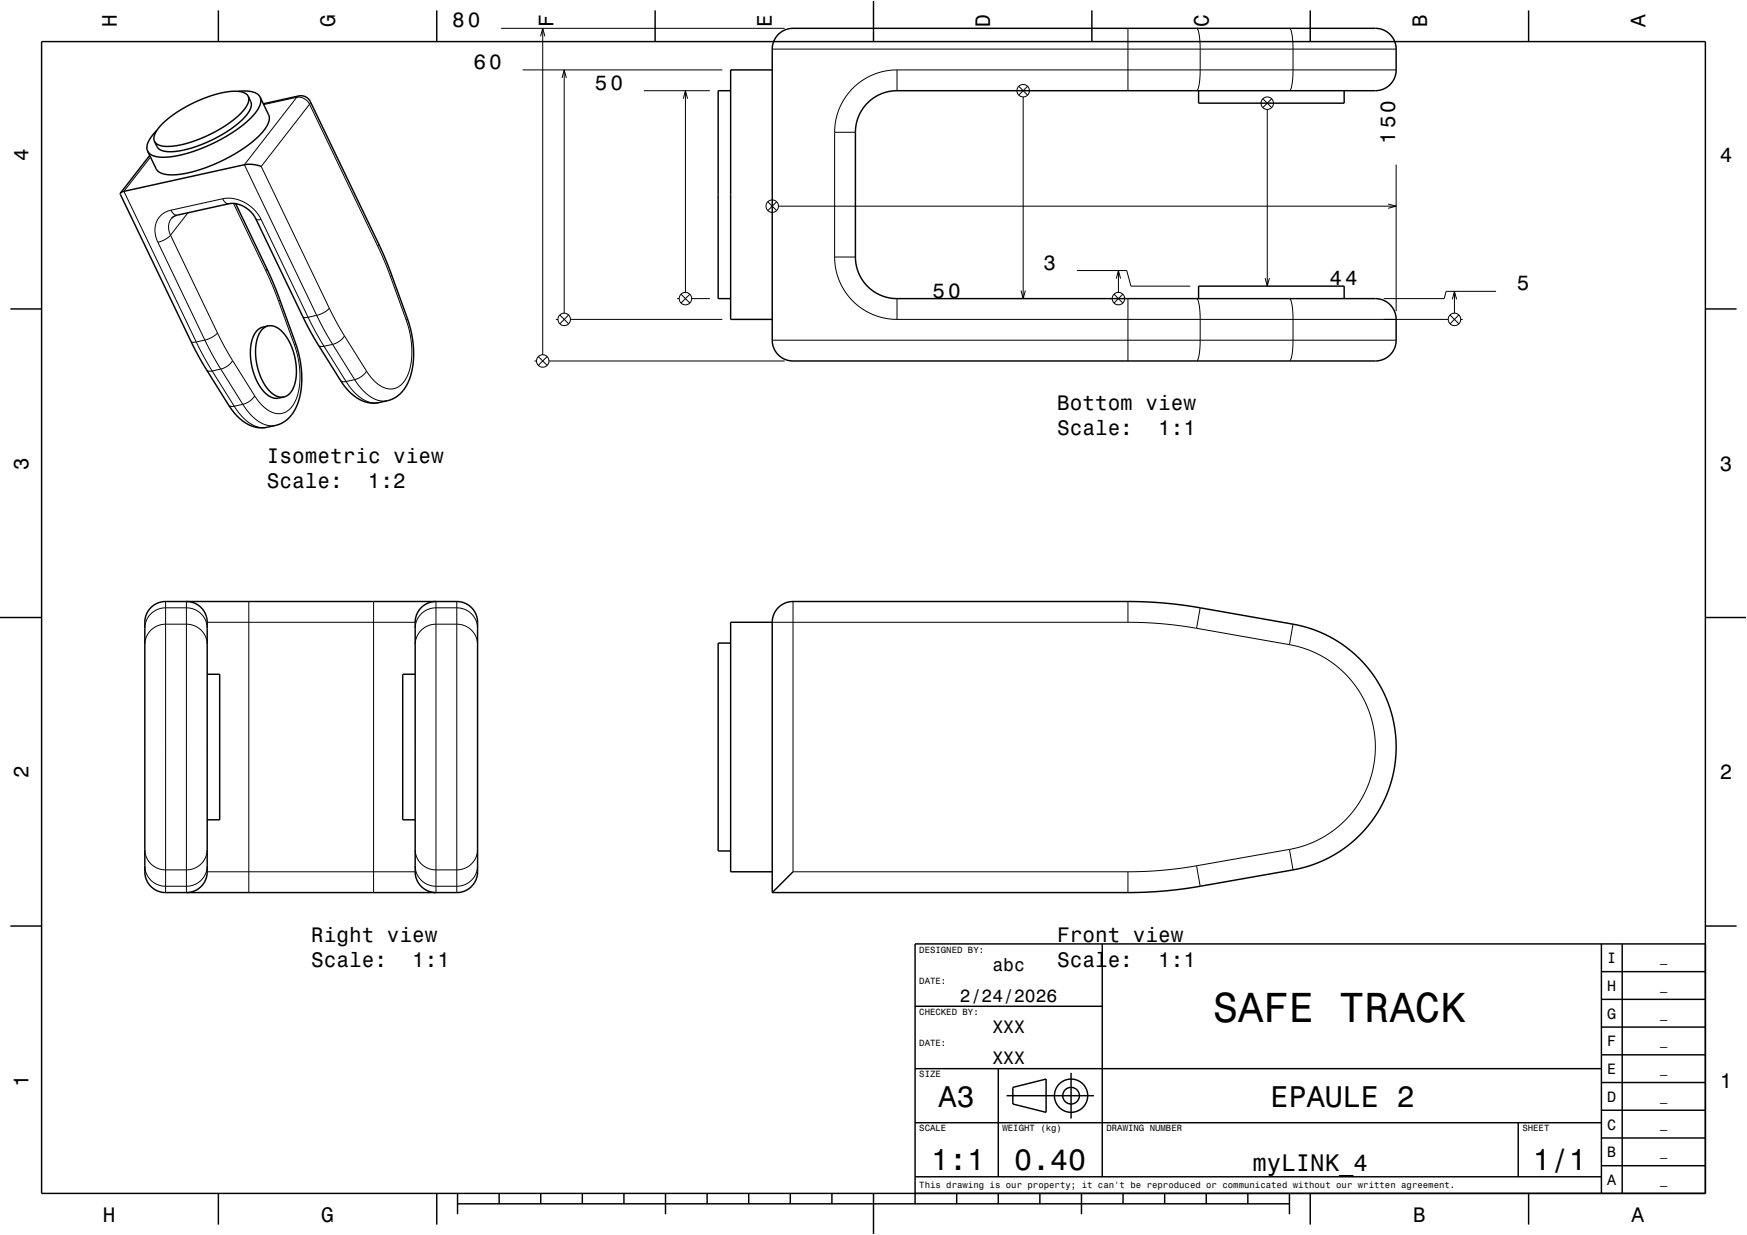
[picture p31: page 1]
CHECKED BY:; Front view; Bottom view Scale: 1:1; Right view Scale: 1:1; Isometric view Scale: 1:2

DESIGNED BY: Scale: 1:1 abc DATE: 2/24/2026 | SAFE TRACK | I | _

SIZE A3 | | | | EPAULE 2

SCALE 1:1 | WEIGHT (kg) 0.40 | DRAWING NUMBER myLINK_4 | SHEET 1/1

This drawing is our property; it can't be reproduced or communicated without our written agreement.

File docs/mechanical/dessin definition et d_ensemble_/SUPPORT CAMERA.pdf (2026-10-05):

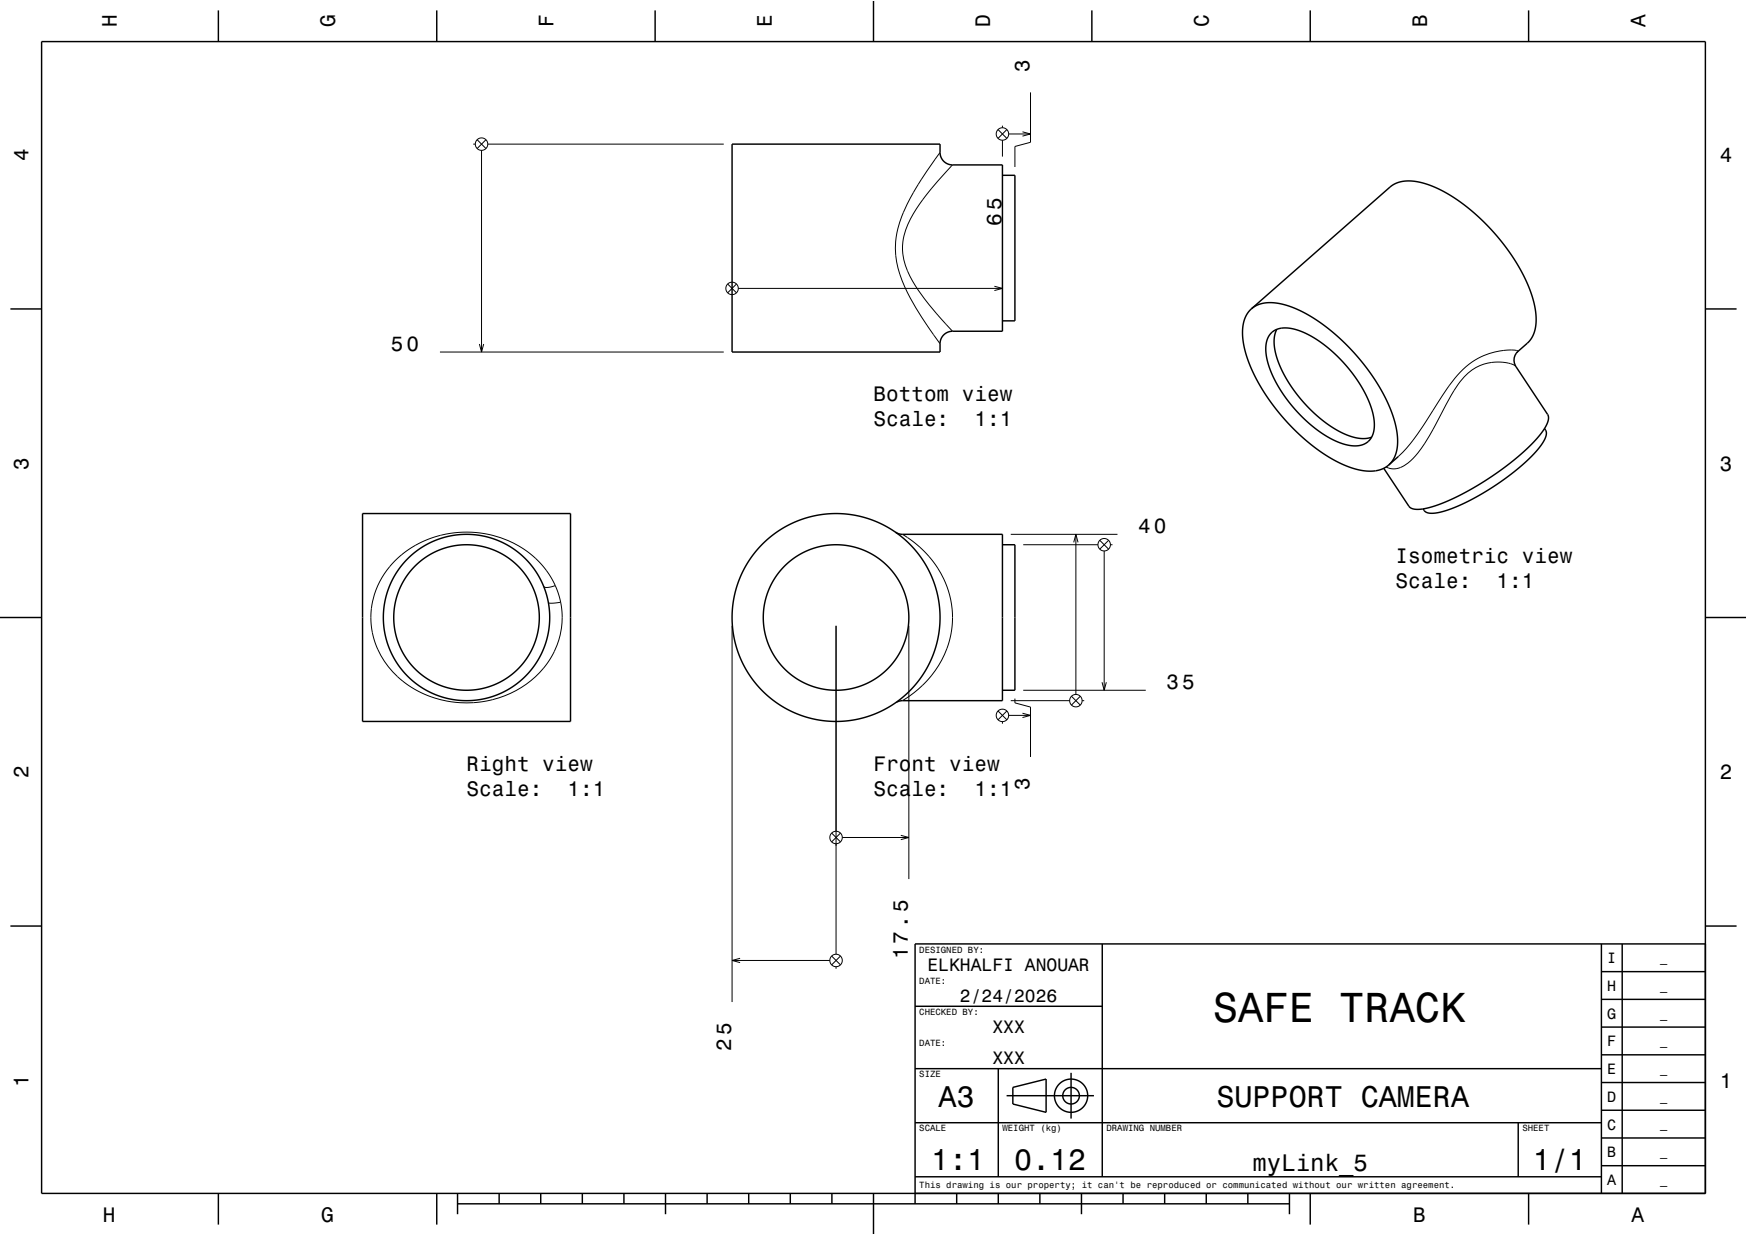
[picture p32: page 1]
CHECKED BY:; Front view Scale: 1:1 17.5; Bottom view Scale: 1:1; Right view Scale: 1:1; Isometric view Scale: 1:1

DESIGNED BY: ELKHALFI ANOUAR DATE: 2/24/2026 | SAFE TRACK | I | _

SIZE A3 | | | | SUPPORT CAMERA

SCALE 1:1 | WEIGHT (kg) 0.12 | DRAWING NUMBER myLink_5 | SHEET 1/1

This drawing is our property; it can't be reproduced or communicated without our written agreement.

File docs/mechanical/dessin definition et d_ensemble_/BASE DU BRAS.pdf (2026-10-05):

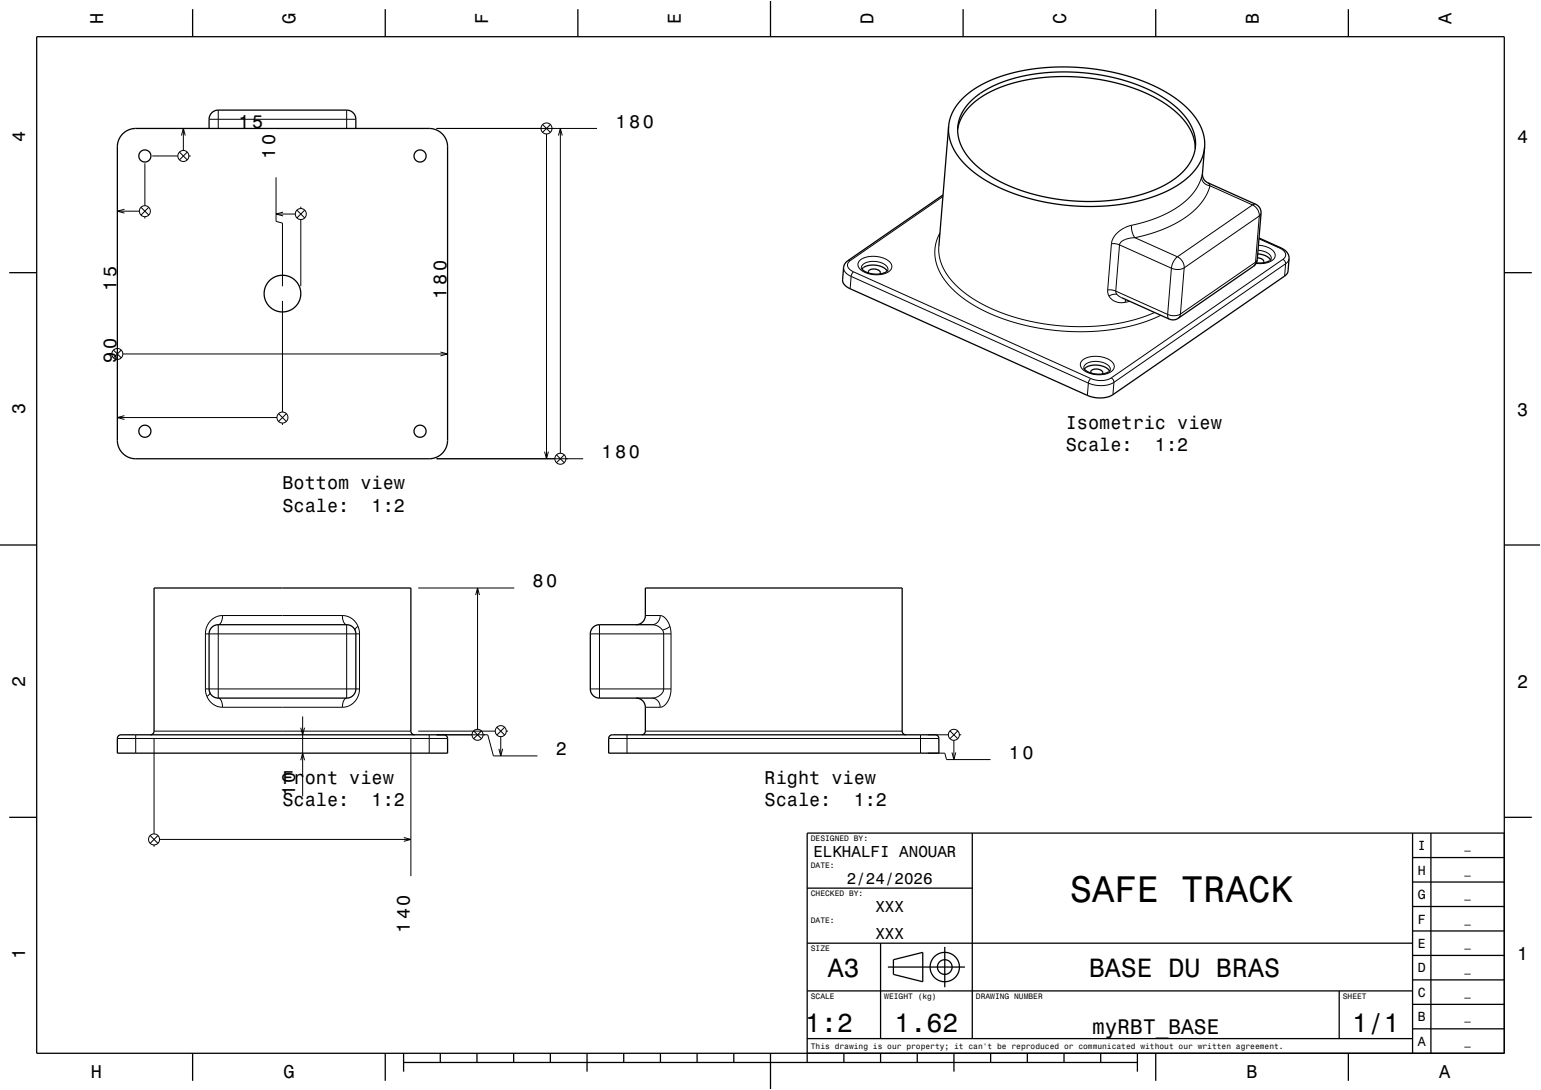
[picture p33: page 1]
CHECKED BY:; Front view Scale: 1:2 140; Bottom view Scale: 1:2; Right view Scale: 1:2; Isometric view Scale: 1:2

DESIGNED BY: ELKHALFI ANOUAR DATE: 2/24/2026 | SAFE TRACK | I | _

SIZE A3 | | | | BASE DU BRAS

SCALE 1:2 | WEIGHT (kg) 1.62 | DRAWING NUMBER myRBT_BASE | SHEET 1/1

This drawing is our property; it can't be reproduced or communicated without our written agreement.

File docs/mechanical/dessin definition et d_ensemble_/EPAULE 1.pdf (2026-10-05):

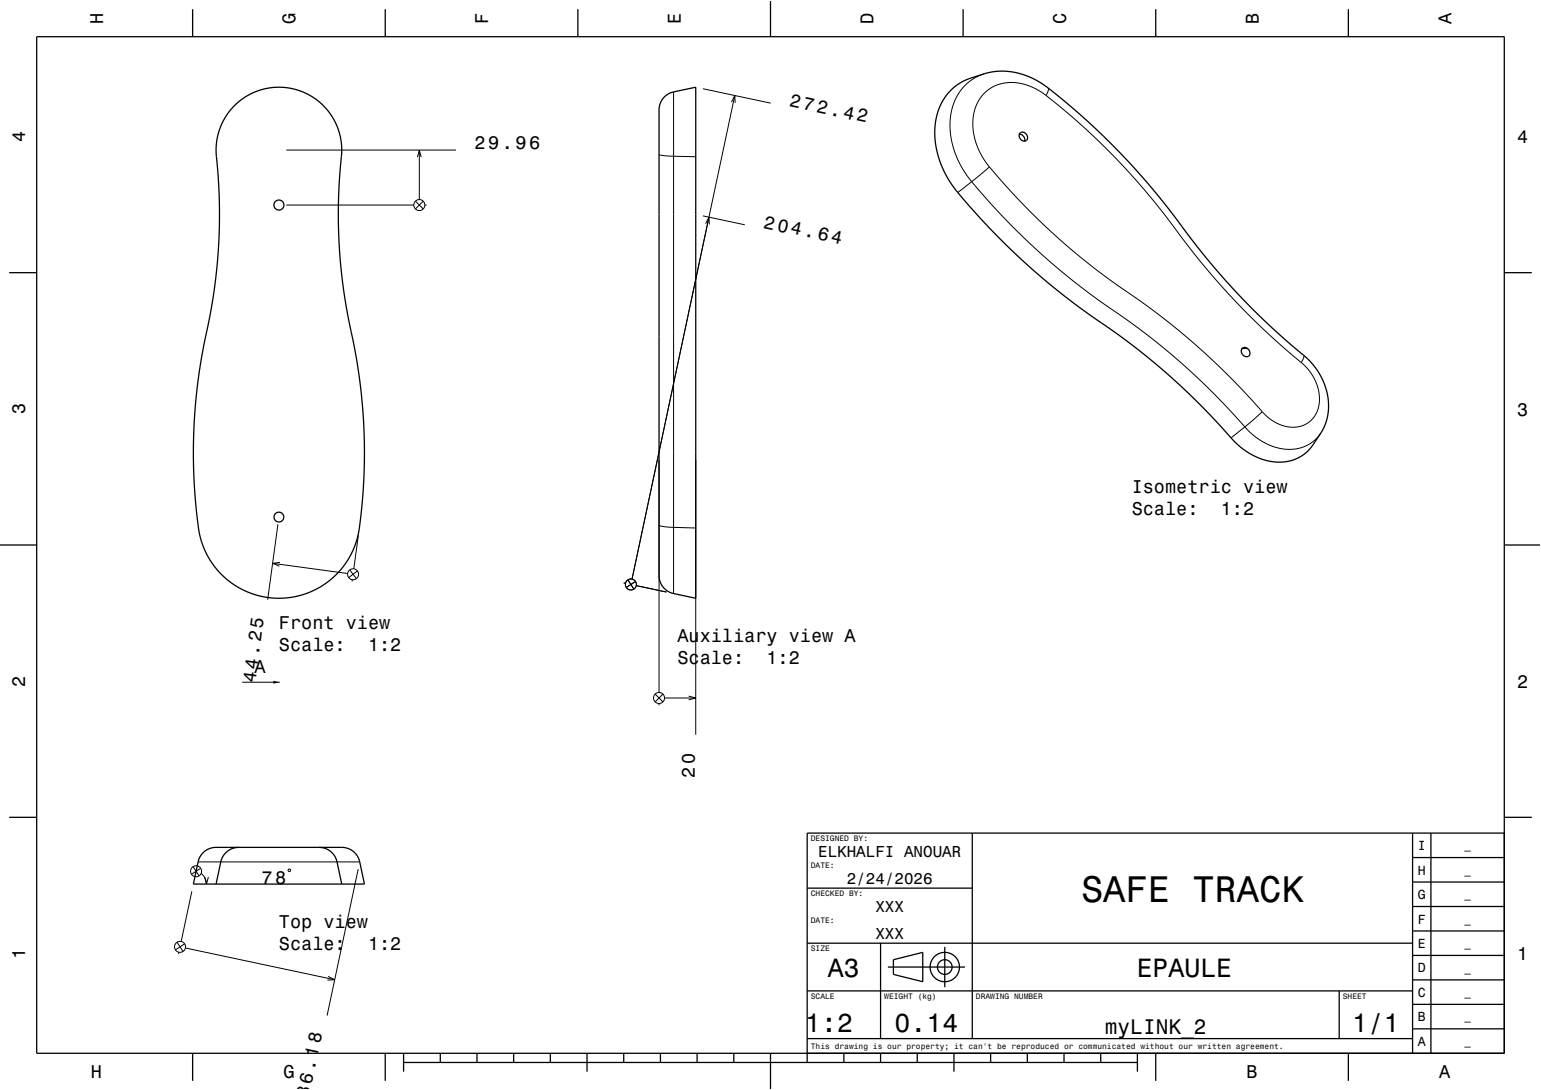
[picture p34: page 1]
CHECKED BY:; Front view Scale: 1:2 44.25; Top view Scale: 1:2; Auxiliary view A Scale: 1:2 20; Isometric view Scale: 1:2

DESIGNED BY: ELKHALFI ANOUAR DATE: 2/24/2026 | SAFE TRACK | I | _

SIZE A3 | | | | EPAULE

SCALE 1:2 | WEIGHT (kg) 0.14 | DRAWING NUMBER myLINK_2 | SHEET 1/1

This drawing is our property; it can't be reproduced or communicated without our written agreement.

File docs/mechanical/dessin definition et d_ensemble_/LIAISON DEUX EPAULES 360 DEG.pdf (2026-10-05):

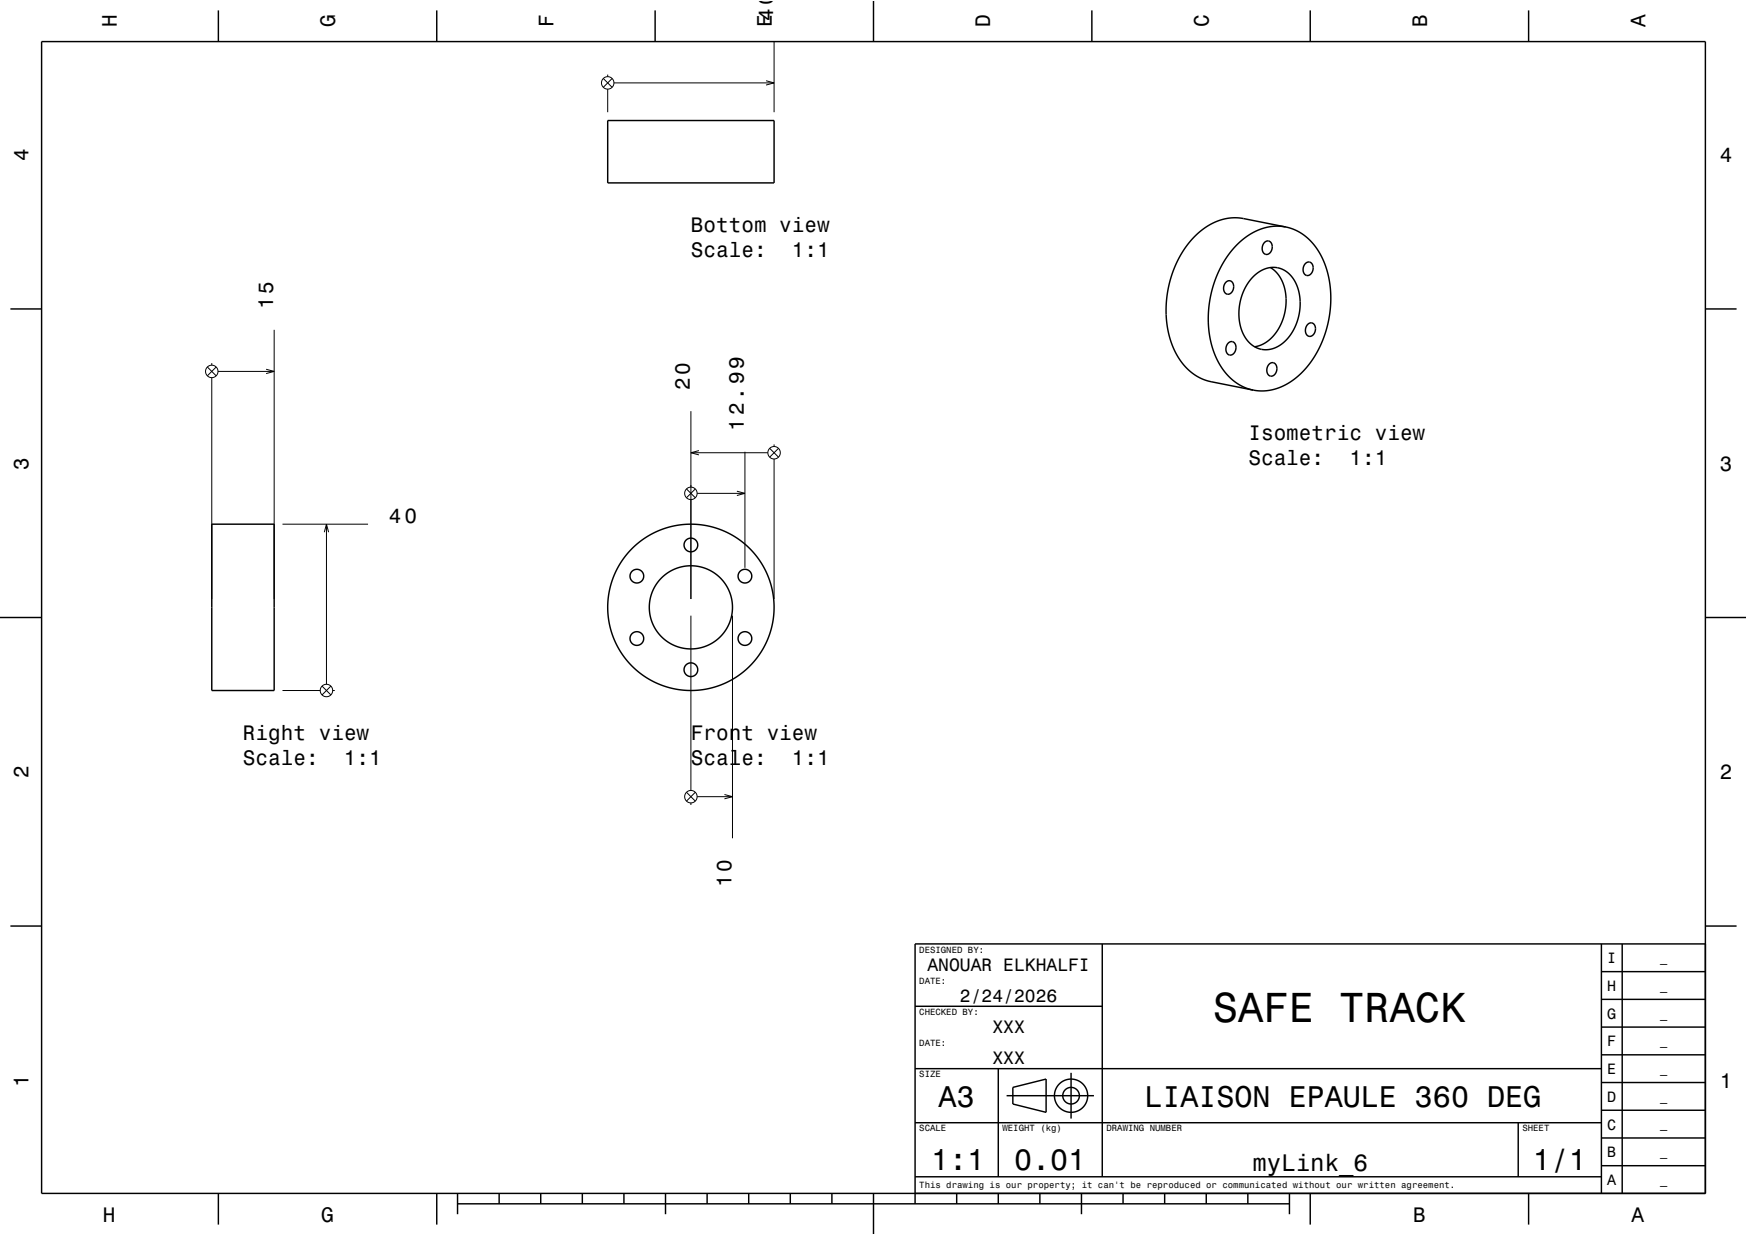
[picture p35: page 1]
CHECKED BY:; Front view Scale: 1:1; Bottom view; Scale: 1:1 40; Right view Scale: 1:1; Isometric view Scale: 1:1

DESIGNED BY: ANOUAR ELKHALFI DATE: 2/24/2026 | SAFE TRACK | I | _

SIZE A3 | | | | LIAISON EPAULE 360 DEG

SCALE 1:1 | WEIGHT (kg) 0.01 | DRAWING NUMBER myLink_6 | SHEET 1/1

This drawing is our property; it can't be reproduced or communicated without our written agreement.

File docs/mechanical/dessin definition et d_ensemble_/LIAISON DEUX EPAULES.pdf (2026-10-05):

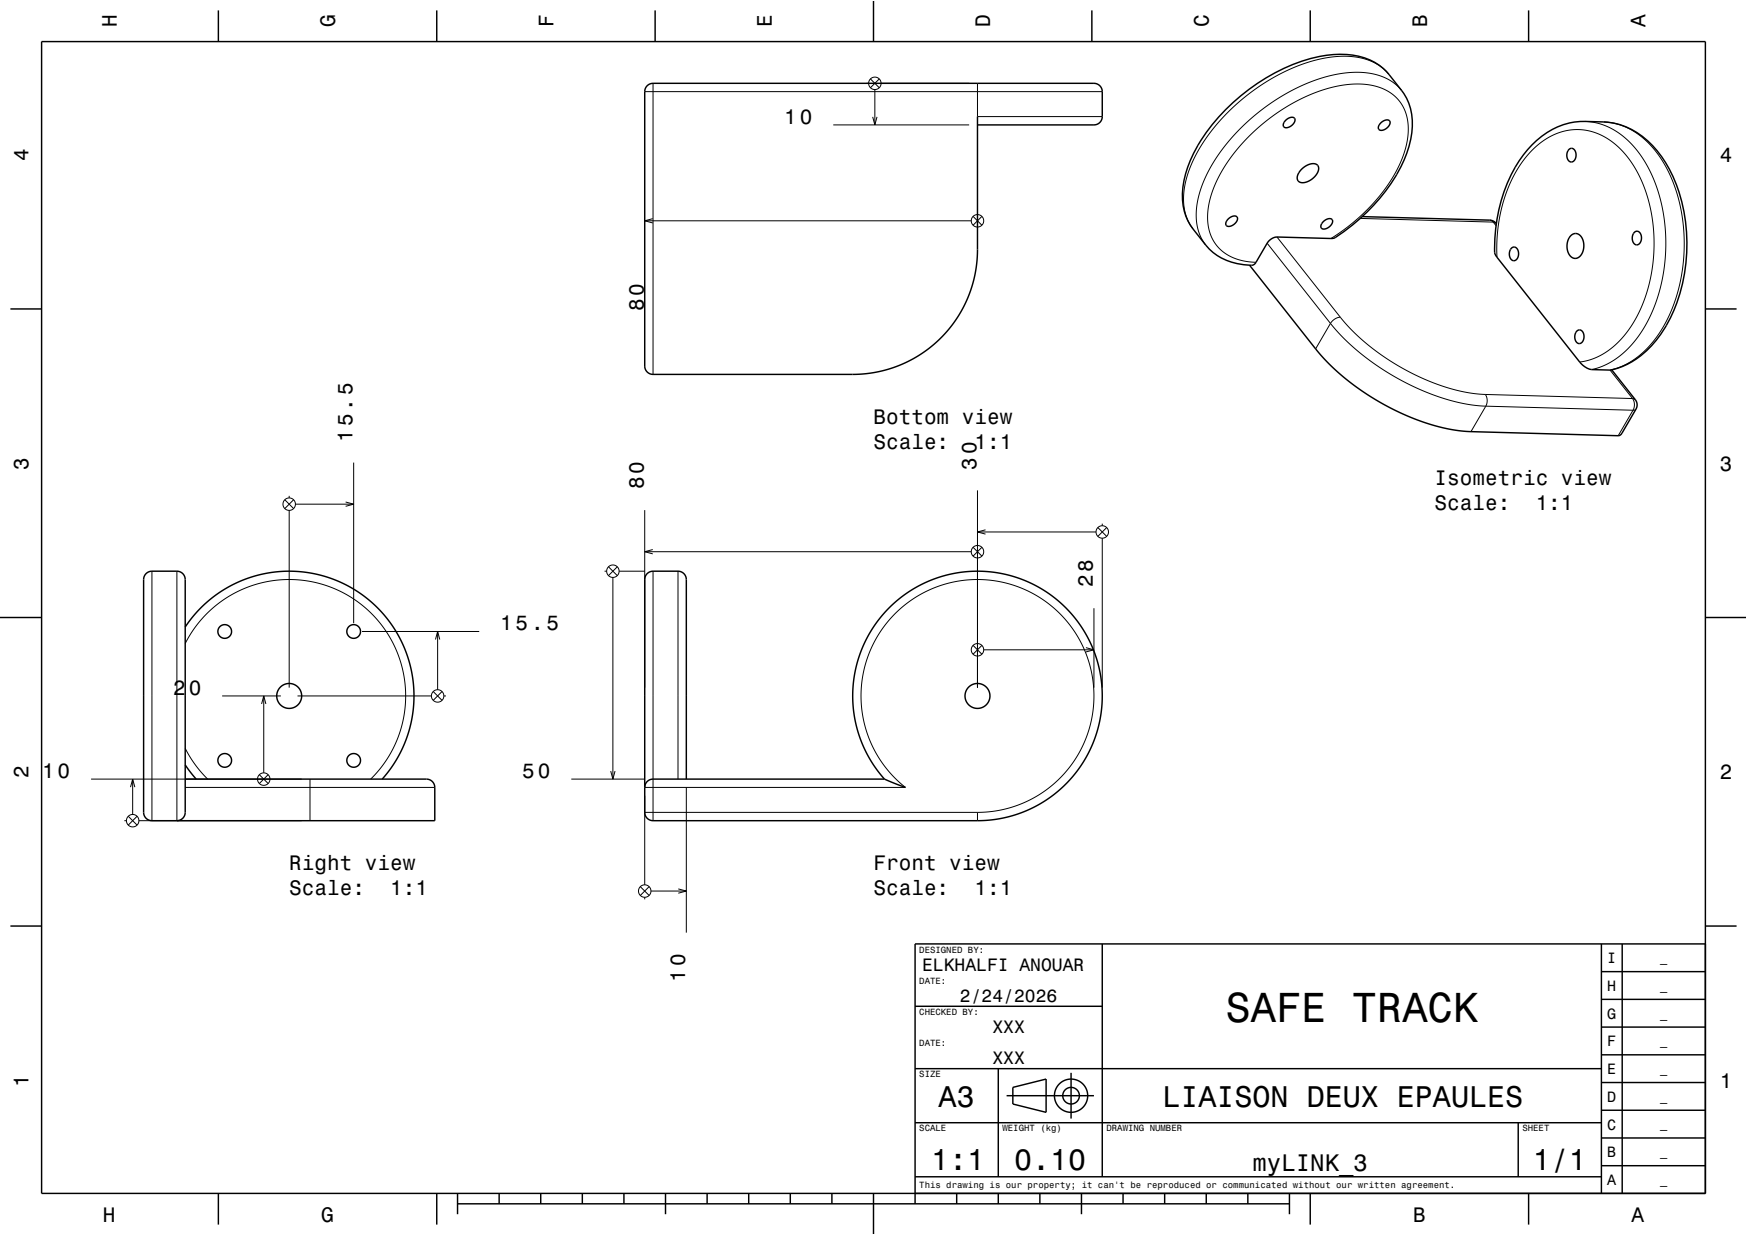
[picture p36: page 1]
CHECKED BY:; Front view; Scale: 1:1 30; Bottom view Scale: 1:1; Right view; Scale: 1:1 15.5; Isometric view Scale: 1:1

DESIGNED BY: ELKHALFI ANOUAR DATE: 2/24/2026 | SAFE TRACK | I | _

SIZE A3 | | | | LIAISON DEUX EPAULES

SCALE 1:1 | WEIGHT (kg) 0.10 | DRAWING NUMBER myLINK_3 | SHEET 1/1

This drawing is our property; it can't be reproduced or communicated without our written agreement.

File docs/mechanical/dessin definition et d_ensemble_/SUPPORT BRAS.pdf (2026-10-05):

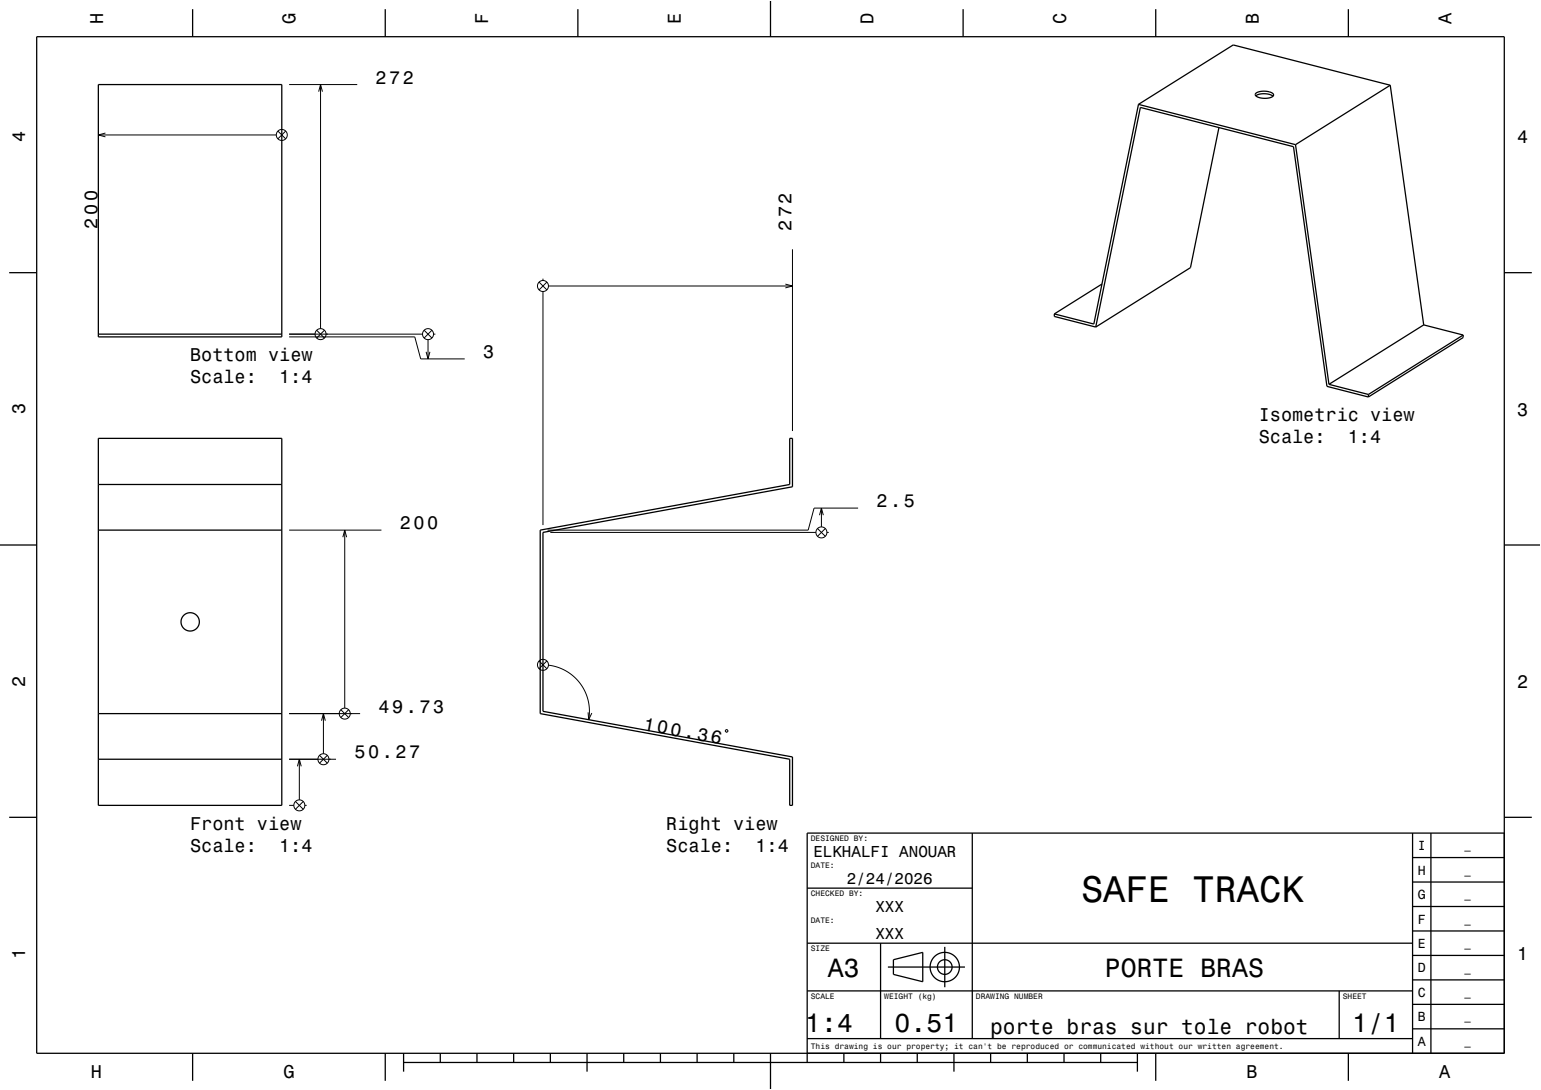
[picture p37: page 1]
CHECKED BY:; Front view Scale: 1:4; Bottom view Scale: 1:4; Right view; Scale: 1:4272; Isometric view Scale: 1:4

DESIGNED BY: ELKHALFI ANOUAR DATE: 2/24/2026 | SAFE TRACK | I | _

SIZE A3 | | | | PORTE BRAS

SCALE 1:4 | WEIGHT (kg) 0.51 | DRAWING NUMBER porte bras sur tole robot | SHEET 1/1

This drawing is our property; it can't be reproduced or communicated without our written agreement.

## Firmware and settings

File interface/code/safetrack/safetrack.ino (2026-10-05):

/*
 * RobotSystem.ino - Main firmware for the robotic arm.
 * 
 * Hardware:
 *   - 2x NEMA17 + 1x NEMA23 on CNC Shield V3
 *   - 2x micro servos (wrist & gripper)
 *   - DHT22 temperature/humidity sensor
 *   - 2x HC-SR04 ultrasonic distance sensors
 * 
 * Publishes the five motor angles (base, shoulder, elbow, wrist, gripper)
 * via serial at 115200 baud, every PUBLISH_INTERVAL milliseconds.
 */

#include "config.h"
#include "types.h"
#include "StepperArm.h"

// ---- Global objects ----
StepperArm stepperArm;
// Placeholders for classes that will be added later:
/*
ServoController servos;
DHT22Sensor dht;
Ultrasonic ultrasonic1, ultrasonic2;
RobotController robot;
Scheduler scheduler;
*/

// ---- Timing for serial publication ----
unsigned long lastPublishTime = 0;

void setup() {
  Serial.begin(SERIAL_BAUD);
  while (!Serial);  // optional for native USB boards

  stepperArm.begin();
  // When implemented:
  // servos.begin();
  // dht.begin();
  // ultrasonic1.begin(TRIG_PIN_1, ECHO_PIN_1);
  // ultrasonic2.begin(TRIG_PIN_2, ECHO_PIN_2);
  // robot.begin(stepperArm, servos, ...);
  // scheduler.begin();

  Serial.println("Robot system initialised.");
}

void loop() {
  // 1. Always update motors (NON-blocking)
  stepperArm.update();

  // 2. Read serial command
  if (Serial.available()) {
    String input = Serial.readStringUntil('\n');
    input.trim();  // 🔥 removes spaces and hidden characters

    Serial.print("Received: [");
    Serial.print(input);
    Serial.println("]");

    // 3. Parse safely (robust method)
    int firstComma = input.indexOf(',');
    int secondComma = input.indexOf(',', firstComma + 1);

    if (firstComma > 0 && secondComma > firstComma) {
      float b = input.substring(0, firstComma).toFloat();
      float s = input.substring(firstComma + 1, secondComma).toFloat();
      float e = input.substring(secondComma + 1).toFloat();

      Serial.println("Parsing OK");

      stepperArm.setTargetAngle(BASE, b);
      stepperArm.setTargetAngle(SHOULDER, s);
      stepperArm.setTargetAngle(ELBOW, e);

    } else {
      Serial.println("❌ Format error! Use: 10,10,10");
    }
  }

  // 4. (Optional) publish angles every 500 ms
  static unsigned long lastPublishTime = 0;
  if (millis() - lastPublishTime >= 500) {

    float base     = stepperArm.getCurrentAngle(BASE);
    float shoulder = stepperArm.getCurrentAngle(SHOULDER);
    float elbow    = stepperArm.getCurrentAngle(ELBOW);

    Serial.print(base, 2);
    Serial.print(",");
    Serial.print(shoulder, 2);
    Serial.print(",");
    Serial.print(elbow, 2);
    Serial.println(",0.00,0.00");

    lastPublishTime = millis();
  }
}

/**
 * @brief Prints the current angles of all five joints as CSV:
 *        base,shoulder,elbow,wrist,gripper
 *        followed by a newline.
 */
void publishJointAngles() {
  JointAngles angles;

  // Stepper joints (angles computed from motor steps)
  angles.base     = stepperArm.getCurrentAngle(BASE);
  angles.shoulder = stepperArm.getCurrentAngle(SHOULDER);
  angles.elbow    = stepperArm.getCurrentAngle(ELBOW);

  // Servo joints – placeholder: read 0.0 until ServoController is ready
  // angles.wrist   = servos.getAngle(WRIST);
  // angles.gripper = servos.getAngle(GRIPPER);
  angles.wrist   = 0.0f;
  angles.gripper = 0.0f;

  // Print in CSV format
  Serial.print(angles.base, 2);
  Serial.print(',');
  Serial.print(angles.shoulder, 2);
  Serial.print(',');
  Serial.print(angles.elbow, 2);
  Serial.print(',');
  Serial.print(angles.wrist, 2);
  Serial.print(',');
  Serial.println(angles.gripper, 2);
}

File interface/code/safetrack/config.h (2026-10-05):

#ifndef CONFIG_H
#define CONFIG_H

// ---- CNC Shield V3 (Arduino Uno) pinout for stepper drivers ----
// We use X, Y, Z axes. Enable is shared, held LOW by default.
#define X_STEP_PIN       2
#define X_DIR_PIN        5
#define Y_STEP_PIN       3
#define Y_DIR_PIN        6
#define Z_STEP_PIN       4
#define Z_DIR_PIN        7
#define STEPPER_ENABLE   8       // Common enable, LOW = enabled

// ---- Microstepping (set by jumpers on the shield) ----
// Assume 1/16 microstepping for all drivers.
#define MICROSTEPS       16
#define STEPS_PER_REV    200     // NEMA17 / NEMA23 standard

// ---- Stepper motor assignments ----
// 0 = base (NEMA17), 1 = shoulder (NEMA17), 2 = elbow (NEMA23)
#define NUM_STEPPERS     3

// ---- Servo pins ----
#define SERVO1_PIN       9
#define SERVO2_PIN       10

// ---- DHT22 sensor ----
#define DHT22_PIN        A4

// ---- HC-SR04 ultrasonic sensors ----
#define TRIG_PIN_1       A0
#define ECHO_PIN_1       A1
#define TRIG_PIN_2       A2
#define ECHO_PIN_2       A3

// ---- Serial communication ----
#define SERIAL_BAUD      115200
#define PUBLISH_INTERVAL 100   // ms between angle publications

// ---- Movement limits ----
#define MAX_ANGLE_DEG    180.0f
#define MIN_ANGLE_DEG    0.0f

#endif

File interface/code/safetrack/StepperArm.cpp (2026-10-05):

#include "StepperArm.h"
#include <Arduino.h>

// ---------------------------------------------------------------------------
// Constructor
// ---------------------------------------------------------------------------
StepperArm::StepperArm()
    : stepperX(AccelStepper::DRIVER, X_STEP_PIN, X_DIR_PIN)
    , stepperY(AccelStepper::DRIVER, Y_STEP_PIN, Y_DIR_PIN)
    , stepperZ(AccelStepper::DRIVER, Z_STEP_PIN, Z_DIR_PIN)
    , stepsPerDegree((float)(STEPS_PER_REV * MICROSTEPS) / 360.0f)
    , enabled(false)
{
}

// ---------------------------------------------------------------------------
// begin() – initialise drivers and motor parameters
// ---------------------------------------------------------------------------
void StepperArm::begin() {
  // Common enable pin: LOW = motors enabled
  pinMode(STEPPER_ENABLE, OUTPUT);
  digitalWrite(STEPPER_ENABLE, LOW);
  enabled = true;

  // Configure each stepper
  AccelStepper* steppers[3] = { &stepperX, &stepperY, &stepperZ };
  for (auto s : steppers) {
    s->setMaxSpeed(400);        // steps per second, adjust to your needs
    s->setAcceleration(200);    // steps per second per second
    s->setCurrentPosition(0);   // assume homed at zero
  }
}

// ---------------------------------------------------------------------------
// setTargetAngle() – request a new angle for a stepper joint
// ---------------------------------------------------------------------------
void StepperArm::setTargetAngle(MotorIndex joint, float angle) {
  angle = clampAngle(angle);
  long targetSteps = angleToSteps(angle);

  AccelStepper* motor = nullptr;
  switch (joint) {
    case BASE:     motor = &stepperX; break;
    case SHOULDER: motor = &stepperY; break;
    case ELBOW:    motor = &stepperZ; break;
    default: return; // invalid joint
  }

  motor->moveTo(targetSteps);
}

// ---------------------------------------------------------------------------
// getCurrentAngle() – convert current motor position back to degrees
// ---------------------------------------------------------------------------
float StepperArm::getCurrentAngle(MotorIndex joint) const {
  long pos = 0;
  switch (joint) {
    case BASE:     pos = stepperX.currentPosition(); break;
    case SHOULDER: pos = stepperY.currentPosition(); break;
    case ELBOW:    pos = stepperZ.currentPosition(); break;
    default: return 0.0f;
  }
  return stepsToAngle(pos);
}

// ---------------------------------------------------------------------------
// update() – non‑blocking call in loop()
// ---------------------------------------------------------------------------
void StepperArm::update() {
  stepperX.run();
  stepperY.run();
  stepperZ.run();
}

// ---------------------------------------------------------------------------
// emergencyStop() – stop all motors immediately, keep them enabled
// ---------------------------------------------------------------------------
void StepperArm::emergencyStop() {
  stepperX.stop();
  stepperY.stop();
  stepperZ.stop();
  // optional: digitalWrite(STEPPER_ENABLE, HIGH); // disable motors
}

// ---------------------------------------------------------------------------
// Private helpers
// ---------------------------------------------------------------------------
long StepperArm::angleToSteps(float angle) const {
  return (long)(angle * stepsPerDegree);
}

float StepperArm::stepsToAngle(long steps) const {
  return (float)steps / stepsPerDegree;
}

float StepperArm::clampAngle(float angle) const {
  if (angle < MIN_ANGLE_DEG) return MIN_ANGLE_DEG;
  if (angle > MAX_ANGLE_DEG) return MAX_ANGLE_DEG;
  return angle;
}

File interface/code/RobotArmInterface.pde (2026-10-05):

// ============================================================================
// ROBOT CONTROL & SENSOR VISUALIZATION INTERFACE
// Processing Application for Arduino-based Robotic Arm
// ============================================================================

import processing.serial.*;

// ============================================================================
// CONFIGURATION
// ============================================================================

final String SERIAL_PORT = "COM3"; // Change to your port (e.g., "/dev/ttyUSB0" on Linux)
final int BAUD_RATE = 115200;
final int GRAPH_HISTORY = 300; // samples to keep in history

// Joint angle constraints
final float[] ANGLE_MINS = {-180, 0, 0, 0, 0};
final float[] ANGLE_MAXS = {180, 180, 180, 180, 180};
final String[] JOINT_NAMES = {"Base", "Shoulder", "Elbow", "Pan", "Tilt"};

// ============================================================================
// GLOBAL STATE
// ============================================================================

Serial serial;
ControlPanel controlPanel;
SensorGraph sensorGraph;
RobotVisualizer robotViz;

float[] targetAngles = {0, 0, 0, 90, 90};
float[] currentAngles = {0, 0, 0, 90, 90};

float temperature = 0;
float humidity = 0;
float distance1 = 0;
float distance2 = 0;

ArrayList<Float> tempHistory = new ArrayList<Float>();
ArrayList<Float> humidityHistory = new ArrayList<Float>();
ArrayList<Float> dist1History = new ArrayList<Float>();
ArrayList<Float> dist2History = new ArrayList<Float>();

boolean connected = false;
String statusMessage = "Disconnected";

// ============================================================================
// SETUP & MAIN LOOP
// ============================================================================

void settings() {
  size(1600, 900);
}

void setup() {
  frameRate(60);
  initializeSerial();
  
  controlPanel = new ControlPanel();
  sensorGraph = new SensorGraph();
  robotViz = new RobotVisualizer();
}

void draw() {
  background(11, 12, 15);
  
  // Update serial communication
  if (connected) {
    readSerialData();
    sendControlCommand();
  }
  
  // Render interface
  controlPanel.display();
  robotViz.display(width * 0.5, 50);
  sensorGraph.display(width * 0.5, height * 0.55);
  
  // Status bar
  drawStatusBar();
}

void keyPressed() {
  if (key == 'r' || key == 'R') {
    // Reset all angles to home position
    targetAngles = new float[]{0, 0, 0, 90, 90};
  }
}

// ============================================================================
// SERIAL COMMUNICATION
// ============================================================================

void initializeSerial() {
  try {
    String[] ports = Serial.list();
    if (ports.length > 0) {
      println("Available ports:", ports);
      for (String port : ports) {
        if (port.contains(SERIAL_PORT) || port.contains("COM") || port.contains("ttyUSB")) {
          serial = new Serial(this, port, BAUD_RATE);
          serial.bufferUntil('\n');
          connected = true;
          statusMessage = "Connected to " + port;
          println("Connected to: " + port);
          return;
        }
      }
      // Fallback: try first port
      if (ports.length > 0) {
        serial = new Serial(this, ports[0], BAUD_RATE);
        serial.bufferUntil('\n');
        connected = true;
        statusMessage = "Connected to " + ports[0];
      }
    }
  } catch (Exception e) {
    println("Serial connection failed:", e.getMessage());
    statusMessage = "Serial Error: " + e.getMessage();
  }
}

void serialEvent(Serial p) {
  String data = p.readStringUntil('\n');
  if (data == null) return;
  
  data = data.trim();
  if (data.length() == 0) return;
  
  try {
    if (data.startsWith("S,")) {
      // Sensor data: S,temp,humidity,dist1,dist2
      String[] parts = data.substring(2).split(",");
      if (parts.length >= 4) {
        temperature = float(parts[0]);
        humidity = float(parts[1]);
        distance1 = float(parts[2]);
        distance2 = float(parts[3]);
        
        sensorGraph.addData(temperature, humidity, distance1, distance2);
      }
    } else {
      // Angle data: base,shoulder,elbow,pan,tilt
      String[] parts = data.split(",");
      if (parts.length >= 5) {
        currentAngles[0] = float(parts[0]);
        currentAngles[1] = float(parts[1]);
        currentAngles[2] = float(parts[2]);
        currentAngles[3] = float(parts[3]);
        currentAngles[4] = float(parts[4]);
      }
    }
  } catch (Exception e) {
    println("Parse error:", data, e.getMessage());
  }
}

void sendControlCommand() {
  // Send target angles as CSV
  String cmd = String.format("%.2f,%.2f,%.2f,%.0f,%.0f\n",
    targetAngles[0], targetAngles[1], targetAngles[2], targetAngles[3], targetAngles[4]);
  
  if (serial != null && serial.available() >= 0) {
    serial.write(cmd);
  }
}

// ============================================================================
// CONTROL PANEL (LEFT SIDE)
// ============================================================================

class ControlPanel {
  
  Slider[] sliders;
  Button homeBtn;
  
  ControlPanel() {
    sliders = new Slider[5];
    for (int i = 0; i < 5; i++) {
      sliders[i] = new Slider(
        30, 80 + i * 140, 300, 120,
        JOINT_NAMES[i],
        ANGLE_MINS[i], ANGLE_MAXS[i],
        (ANGLE_MINS[i] + ANGLE_MAXS[i]) / 2
      );
    }
    homeBtn = new Button(30, 800, 300, 50, "HOME POSITION");
  }
  
  void display() {
    // Panel background
    fill(18, 19, 23);
    stroke(45, 48, 56);
    strokeWeight(1);
    rect(0, 0, width * 0.45, height);
    
    // Title
    fill(255);
    textFont(createFont("Courier", 18));
    textAlign(LEFT);
    text("JOINT CONTROL", 30, 40);
    
    // Sliders
    for (int i = 0; i < 5; i++) {
      targetAngles[i] = sliders[i].display();
    }
    
    // Home button
    homeBtn.display();
    if (homeBtn.isPressed()) {
      for (int i = 0; i < 5; i++) {
        targetAngles[i] = ANGLE_MAXS[i] / 2;
      }
    }
    
    // Status info
    fill(100, 200, 100);
    textSize(12);
    textAlign(LEFT);
    text("R - Reset to Home", 30, 860);
  }
}
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
